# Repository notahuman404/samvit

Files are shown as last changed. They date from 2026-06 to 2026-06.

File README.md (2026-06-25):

# Samvit 👁️🌉

> *Samvit (संवित्) — Sanskrit for "Conscious Awareness"*

> **"We don't just navigate the system for blind users — we navigate the world."**

An AI-powered assistive system that helps visually impaired individuals independently find, understand, and physically reach public services — starting with healthcare.

---

## 🧩 The Problem

Visually impaired individuals face **two walls**, not one:

1. They can't independently navigate apps or screens to find nearby healthcare, benefits, or public services
2. Even when someone helps them find it — **they still can't get there alone**

Existing solutions solve neither problem completely. Screen readers tell you *what's on screen* but don't help you *understand* or *act*. Navigation apps help sighted people. Nothing bridges both worlds.

---

## 💡 The Solution

Samvit is a **two-layer assistive system** combining AI software and sensory hardware:

### 🧠 Layer 1 — Software (The Brain)
A Jarvis-like voice AI that understands your phone screen and the web on your behalf.

- Say *"Find me the nearest free clinic"* — it searches, reads, filters, and explains results in plain language
- Guides users through benefits eligibility questions conversationally
- Makes phone calls on command (*"Call the clinic and ask if they take walk-ins"*)
- Reads and interprets any screen content aloud with context, not just raw text

### 👁️ Layer 2 — Hardware (The Game-Changer)
A wearable sensory substitution device inspired by Neil Harbisson's pioneering work in human sensory extension.

- Uses **heatmapping** to translate the visual environment into sensory feedback
- Converts spatial information (obstacles, paths, destinations) into perceivable signals
- Allows the user to **physically navigate** to their destination — independently, without a guide
- Works in real-time alongside the software layer for end-to-end assistance

---

## 🎯 Challenge Alignment

**Brief 4 — Public Service, Direction A: Benefits Navigator**

| Requirement | Samvit |
|---|---|
| Help users interpret rules and reduce confusion | ✅ Voice AI simplifies eligibility criteria in plain language |
| Translate criteria into plain language | ✅ Reads and contextualizes screen content aloud |
| Ask questions to guide users through their situation | ✅ Conversational AI walks users step by step |
| Healthcare as a primary use case | ✅ Core use case of the product |
| Go beyond a directory — help users actually act | ✅ Hardware ensures they can physically reach the service |

---

## 🏗️ Architecture Overview

```
User Voice Input
      │
      ▼
┌─────────────────────┐
│   Voice AI Layer    │  ← Understands intent, reads screen, navigates web
│  (Jarvis Engine)    │
└────────┬────────────┘
         │
         ▼
┌─────────────────────┐
│  Screen & Web       │  ← Finds clinics, reads eligibility, makes calls
│  Understanding      │
└────────┬────────────┘
         │
         ▼
┌─────────────────────┐
│  Hardware Layer     │  ← Heatmap-based sensory substitution wearable
│  (Sensory Bridge)   │    guides user to physical destination
└─────────────────────┘
```

---

## 🔬 Inspiration

- **Neil Harbisson** — Pioneer of sensory substitution; the first human officially recognized as a cyborg, who perceives color through sound via his "eyeborg" antenna
- **Sensory Substitution Research** — The science of routing one sense's information through another (e.g., visual data → tactile or auditory feedback)
- **Heatmap Navigation** — Using thermal/spatial density mapping to encode environmental information into perceivable signals

---

## 🔩 Hardware Validation & Testing

Our hardware pipeline — from depth sensing through motor actuation — has been validated through a **datasheet-driven simulation** that goes well beyond simple mocking. Rather than stubbing out I2C calls and calling it tested, we built physically-accurate models of every component in the signal chain and ran them against the actual firmware logic.

### What we validated

| Component | Validation Method |
|---|---|
| Intel RealSense D435i depth cameras | Noise model fitted to Intel's published accuracy data: quadratic noise growth (σ = 2mm at 1m, 8mm at 2m, 32mm at 4m), distance-dependent dropout rates, edge artifacts, flying pixel simulation |
| NXP PCA9685 motor drivers (×9) | Full I2C protocol verification against datasheet Rev.4: init sequence timing, register payload format, ALLCALL broadcast, 65-byte raw writes (bypassing SMBus 32-byte cap) |
| Dual-camera depth fusion | Min-distance overlap logic with statistically-verified output across 100+ noisy frames. Invalid readings (0) never corrupt fusion — verified with 50,000 samples |
| 144-motor grid (12×12) | Bijective channel mapping (144 → 9 boards × 16 channels), single-motor precision addressing, rapid on/off cycling stability |
| I2C bus (BCM2711 BSC, 400kHz) | Timing budget calculated from first principles (9 clocks/byte × 400kHz), bus utilization analysis, clock stretching model |

### Fault injection (not just happy-path)

The simulation injects real hardware failures and verifies graceful degradation:

- **Board failure isolation** — one PCA9685 dies, the other 8 continue operating (128/144 motors still active)
- **Brown-out detection** — supply drops below 2.7V, bus operations halt safely before corrupting registers
- **Stuck I2C bus** — SCL held low (common with loose connections), detected and reported within one transaction attempt
- **Bus contention (NACK storms)** — 5% random NACK rate with retry logic achieves 100% frame delivery
- **Thermal performance** — I2C transactions validated at 70°C operating temperature with oscillator drift model

### Stress testing

- **1,000 continuous frames** with dynamically moving obstacles — zero errors, 0.28ms avg loop time (99.4% headroom on 50ms budget)
- **500 rapid on/off cycles** — verifies register write stability under worst-case duty cycling
- **Bug regression suite** — 3 previously-identified firmware bugs verified fixed (SMBus cap #11, ALLCALL bit #12, invalid-depth mapping #13)

### How to run

```bash
cd hardware/tests
python hil_simulation.py --verbose
```

Outputs a structured JSON report (`hil_results.json`) suitable for CI integration, with per-test metrics, timing data, and pass/fail status.

---

## 🚀 MVP Scope

**Phase 1 — Software MVP**
- [x] Voice-activated screen reader with contextual understanding
- [x] Healthcare clinic finder with eligibility pre-screening
- [x] Conversational benefits guidance flow
- [x] One-tap call routing to clinics/services
- [x] Agentic flow: multi-step goal execution with voice control

**Phase 2 — Hardware Prototype**
- [x] Wearable sensor unit (C++ firmware, ARM-compiled)
- [x] Heatmap generation from dual depth cameras
- [x] Sensory feedback output (144 vibration motors, 12×12 grid)
- [x] Integration with software navigation layer
- [x] Hardware validation suite (22 tests, datasheet-verified)

---

## 👥 Target Users

- Visually impaired individuals (partial or full vision loss)
- Blind individuals navigating public services independently
- Families assisting visually impaired members remotely
- Community organizations supporting disability access

---

## 🌍 Impact

Every other Benefits Navigator is just an app. Samvit goes further:

- **Finds** the nearest relevant service
- **Explains** eligibility in plain language
- **Calls** on your behalf
- **Gets you there** — physically, independently

This isn't just accessibility software. It's **independence as a service.**

---

## 🛠️ Running Locally

### Prerequisites

- [Android Studio](https://developer.android.com/studio) (Ladybug or newer recommended)
- Python 3.10+ (for backend)
- A [Gemini API key](https://aistudio.google.com/apikey) (free tier works)
- A `google-services.json` from your GenAI project (for GenAI AI SDK)

### Step 1 — Clone the repo

```bash
git clone https://github.com/mrehan0516/Vision_Guide.git
cd Vision_Guide
```

### Step 2 — Set up the Gemini API key

Create a `.env` file in the project root (same level as `settings.gradle.kts`):

```bash
cp .env.example .env
```

Edit `.env` and replace the placeholder with your real key:

```
GEMINI_API_KEY=your_actual_gemini_api_key_here
```

This key is used by both the Android app (via the Secrets Gradle Plugin) and the Python backend.

### Step 3 — GenAI setup

Place your `google-services.json` file in the `app/` directory. You can get this from your [GenAI Console](https://console.firebase.google.com/) → Project Settings → General → Your Apps → Download `google-services.json`.

### Step 4 — Run the Android app

1. Open Android Studio
2. Select **Open** and choose the `Vision_Guide` directory
3. Let Gradle sync complete (it will download all dependencies automatically)
4. If you see a signing config error, remove this line from `app/build.gradle.kts`:
   ```
   signingConfig = signingConfigs.getByName("debugConfig")
   ```
5. Connect a physical Android device (recommended — accessibility features work best on real devices) or start an emulator
6. Click **Run** (green play button) or press `Shift+F10`

> **Note:** The app uses a `MockVisionPilotClient` by default, so it works without the backend running. The mock simulates the full agent plan → step → confirm flow for demo purposes.

### Step 5 — Run the backend (optional, for full Gemini-powered agent)

```bash
cd backend
pip install fastapi uvicorn google-generativeai pydantic
```

Set the API key in your terminal:

```bash
export GEMINI_API_KEY=your_actual_gemini_api_key_here
```

Start the server:

```bash
python main.py
```

The backend runs on `http://localhost:8000`. API docs are available at `http://localhost:8000/docs`.

### Step 6 — Run the hardware simulation (no hardware needed)

```bash
cd hardware/tests
python hil_simulation.py --verbose
```

This runs the full 22-test HIL validation suite and outputs results to `hil_results.json`.

### Quick reference — what runs where

| Component | How to run | Needs hardware? |
|---|---|---|
| Android app (mock mode) | Android Studio → Run | No (phone or emulator) |
| Android app (live agent) | Android Studio → Run + backend on | No (phone + laptop) |
| Backend API | `python main.py` | No |
| Hardware simulation | `python hil_simulation.py` | No |
| Haptic vest firmware | `./haptic_vest` (on RPi4) | Yes (RPi4 + cameras + motors) |

---

## 🙏 Credits & Acknowledgments

### AI Tools Used in Development

| Tool | Role | Tier |
|---|---|---|
| **Google Gemini 2.0 Flash** | Core AI backbone — powers the agentic reasoning engine, screen understanding, multimodal vision (screenshot OCR), goal decomposition, and step planning | Free tier |
| **Devin** (by Cognition AI) | AI software engineer — built the C++ firmware port, HIL simulation suite, agentic backend (`agent.py`), and Android integration | Free tier |
| **Claude** (by Anthropic) | AI assistant — helped with architecture planning, code review, and documentation | Free tier |

### Open-Source Libraries & Frameworks

**Android App:**
| Library | Purpose |
|---|---|
| [Jetpack Compose](https://developer.android.com/jetpack/compose) | Declarative UI framework |
| [GenAI AI](https://firebase.google.com/docs/vertex-ai) | Gemini model access via GenAI |
| [Retrofit](https://square.github.io/retrofit/) + [OkHttp](https://square.github.io/okhttp/) | HTTP client for backend communication |
| [Moshi](https://github.com/square/moshi) | JSON serialization |
| [CameraX](https://developer.android.com/training/camerax) | Camera capture pipeline |
| [Kotlin Coroutines](https://kotlinlang.org/docs/coroutines-overview.html) | Async/concurrent programming |
| [Accompanist Permissions](https://google.github.io/accompanist/permissions/) | Runtime permission handling |
| [Room](https://developer.android.com/training/data-storage/room) | Local database |
| [Navigation Compose](https://developer.android.com/jetpack/compose/navigation) | In-app navigation |

**Backend (Python):**
| Library | Purpose |
|---|---|
| [FastAPI](https://fastapi.tiangolo.com/) | REST API framework |
| [google-generativeai](https://github.com/google-gemini/generative-ai-python) | Gemini API client |
| [Pydantic](https://docs.pydantic.dev/) | Data validation & serialization |
| [Uvicorn](https://www.uvicorn.org/) | ASGI server |

**Hardware Firmware (C++):**
| Library | Purpose |
|---|---|
| [Intel RealSense SDK (librealsense2)](https://github.com/IntelRealSense/librealsense) | Dual D435i depth camera capture |
| [CMake](https://cmake.org/) | Cross-platform build system |
| C++ Standard Library (`std::thread`, `std::mutex`) | Threading & synchronization |
| Linux I2C (`i2c-dev`, `I2C_RDWR` ioctl) | Raw I2C communication with PCA9685 boards |

**Hardware Components:**
| Component | Spec |
|---|---|
| Raspberry Pi 4B | Cortex-A72, BCM2711, I2C Fast Mode (400kHz) |
| Intel RealSense D435i (×2) | Stereo depth cameras, 640×480 @ 30fps |
| NXP PCA9685 (×9) | 16-channel 12-bit PWM drivers |
| ERM Vibration Motors (×144) | 12×12 haptic grid, 3V/75mA each |

### Methodology Note

The hardware simulation (`hardware/tests/hil_simulation.py`) uses noise models and timing parameters derived from published datasheets — not arbitrary mock values. All protocol sequences were validated against NXP PCA9685 Datasheet Rev.4 (2015) and Intel RealSense D435i specifications (2019).

---

## 📄 License

MIT License — Open for contribution and community development.

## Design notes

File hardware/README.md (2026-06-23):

# Haptic Feedback Vest — Hardware Design

144-channel vibrotactile vest driven by a Raspberry Pi 4, two Intel RealSense D435i depth cameras, and nine PCA9685 PWM controllers switching AO3400A MOSFETs into Precision Microdrives 310-113 ERM coin motors.

## Directory Layout

```
hardware/
├── README.md                       ← this file
├── bom/
│   ├── bom-master.csv              ← full consolidated BOM
│   └── bom-notes.md                ← sourcing notes, substitutions, tolerances
├── schematics/
│   ├── top-level-block-diagram.md  ← system block diagram (ASCII)
│   ├── motor-driver-cell.md        ← single MOSFET driver cell (repeat ×144)
│   ├── pca9685-chain.md            ← I2C chain and addressing
│   ├── power-tree.md               ← full power distribution tree
│   └── raspberry-pi-pinout.md      ← Pi GPIO assignments
├── assembly/
│   ├── assembly-guide.md           ← step-by-step build sequence
│   ├── motor-grid-layout.md        ← 12×12 grid, numbering, spacing
│   └── connector-plan.md           ← JST, FFC, USB connector specs
├── firmware-notes/
│   ├── motor-addressing.md         ← PCA9685 → motor index mapping
│   └── latency-budget.md           ← pipeline timing to hit <50 ms
└── tests/
    └── validation-procedures.md    ← hardware smoke tests and validation
```

## Quick-Start Summary

| Item | Value |
|---|---|
| Haptic channels | 144 |
| Motor grid | 12 × 12 |
| PWM controllers | 9 × PCA9685 (I2C) |
| MOSFET switches | 144 × AO3400A |
| Depth sensors | 2 × Intel RealSense D435i (USB 3) |
| Compute | Raspberry Pi 4 4 GB |
| Audio amp | MAX98357A (I2S) |
| Motor supply | 3 V rail |
| Logic supply | 5 V rail |
| Estimated peak draw | ~31 W |
| Estimated average draw | ~16 W |
| Target power bank | 65 W USB-C PD, ≥ 20 000 mAh |
| Target end-to-end latency | < 50 ms |

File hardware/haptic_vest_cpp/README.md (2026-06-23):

# Haptic Vest C++ — Production Port

C++ port of the Python haptic vest control pipeline (Raspberry Pi 4, dual Intel RealSense D435i, 9× PCA9685, 144 ERM motors).

## Building (on Raspberry Pi 4 / ARM Linux)

```bash
sudo apt install cmake librealsense2-dev
mkdir build && cd build
cmake ..
make -j4
```

The binary is `build/haptic_vest`.

## Usage

```bash
# Real hardware (Pi with cameras + I2C boards):
./haptic_vest

# Mock mode (no hardware):
./haptic_vest --mock

# Options:
./haptic_vest --mock -n 100 -v          # 100 iterations, verbose stats
./haptic_vest --hz 30                   # 30 Hz loop rate
./haptic_vest --upper-serial XXXX --lower-serial YYYY
```

## File Layout

| File | Description |
|---|---|
| `config.h` | All shared constants (grid size, I2C addresses, PCA9685 registers, thresholds) |
| `camera_fusion.h/.cpp` | Threaded dual D435i capture + min-distance overlap fusion |
| `depth_processing.h/.cpp` | Depth grid → motor intensity mapping with invalid-pixel masking |
| `motor_driver.h/.cpp` | PCA9685 I2C driver using raw `I2C_RDWR` ioctl (no SMBus 32-byte cap) |
| `connector.h/.cpp` | Master orchestrator: init → loop → shutdown |
| `main.cpp` | CLI entry point with signal handling |
| `CMakeLists.txt` | Build configuration |
| `compiled/` | Pre-compiled binary (built on x86_64 Ubuntu 22.04; rebuild on Pi for ARM) |

## Behavioral Differences from Python Version

1. **Downsampling moved into CameraSource**: In Python, `DualCameraFusion.get_fused_grid()` calls `_downsample_to_grid()` on each raw frame. In C++, each `RealSenseCamera` downsamples inside its capture thread (before writing to the shared buffer), so the main loop never touches raw high-resolution frames. This reduces lock contention and avoids copying large frames across threads.

2. **No `pyrealsense2` wrapper — uses librealsense2 C++ API directly**: Same SDK, just the native C++ bindings instead of the Python wrapper. Behavior is identical.

3. **I2C uses `I2C_RDWR` ioctl directly**: Python used `smbus2.i2c_msg.write()` which internally does the same ioctl. The C++ version calls `ioctl(fd, I2C_RDWR, ...)` directly — identical wire behavior, no library dependency.

4. **Performance**: Mock-mode loop time is ~0.03 ms (vs ~2.75 ms in Python). Real-hardware I2C timing will be identical (I2C bus speed is the bottleneck, not CPU).

5. **No `--diag` mode**: The Python `connector.py` had a `--diag` flag that scanned the I2C bus. The C++ port omits this — use `i2cdetect -y 1` directly on the Pi instead.

6. **Signal handling**: Uses `std::signal(SIGINT/SIGTERM)` for clean shutdown. Same behavior as the Python version's signal handler.

## Note on Pre-compiled Binary

The binary in `compiled/` was built on **x86_64 Ubuntu 22.04** (Devin's build environment). You must **rebuild on your Raspberry Pi 4** (ARM) for it to run on the actual hardware. The source code and CMakeLists.txt are ready for a Pi build with no changes needed.

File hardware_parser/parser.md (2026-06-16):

# HWDL — Hardware Description Language Specification
## Version 1.0 | Compiler Design & Language Reference

---

## 1. Language Goals

### What HWDL Is

HWDL (Hardware Description Language) is a **strict, declarative DSL** for describing electronic hardware at the logical schematic level. It captures:

- Component definitions (parts) and their pin interfaces
- Power domains and their electrical properties
- Named net connectivity between component pins
- Modules (reusable subsystems) containing instances and connections
- Constraints, placement hints, routing hints, and simulation/validation metadata
- Compile targets that downstream tooling (schematic, PCB, netlist generators) will consume

HWDL is designed to be generated by AI agents and parsed by deterministic compiler tooling. Every construct has a single, unambiguous interpretation.

### What HWDL Is Not

- Not an RTL/HDL language (no Verilog/VHDL behavioral semantics)
- Not a netlist format (HWDL compiles *to* a structured IR from which netlists are generated)
- Not a PCB layout tool (placement/routing hints are advisory only)
- Not a simulation language (simulation blocks carry metadata for external tools)
- Not a schematic drawing tool (topology only; visual layout is downstream)

### Design Principles

1. **No ambiguity**: every syntactic construct has exactly one parse.
2. **No implicit behavior**: all connections, domains, and references are explicit.
3. **Fail loudly**: invalid input produces a precise, located diagnostic.
4. **AI-safe**: structure prevents generation of syntactically plausible but semantically broken designs.
5. **Minimal surface area**: every keyword earns its place.

---

## 2. Syntax Design

### Choice: Custom Block Syntax (Curly-Brace / Semicolon)

| Option | Rejected reason |
|---|---|
| YAML | Significant whitespace causes generation errors; no block comments; indentation levels fragile |
| JSON | No comments; extremely verbose; no typed physical values; no procedural constructs |
| TOML | Flat tables only; no nested block structure needed for hierarchical modules |
| S-expressions | Unfamiliar to engineers; parenthesis matching fragile for AI generation |
| **Custom** | Explicit braces for scope; semicolons for statement termination; no significant whitespace; physical units as first-class literals; minimal keyword set |

The syntax is deterministic for recursive-descent parsing. No backtracking is needed.

### Minimal Complete Example

```hwdl
hwdl 1.0;

// === Part declarations (component library entries) ===

part "ATmega328P" {
    vendor: "Microchip";
    package: "DIP-28";
    datasheet: "https://example.com/atmega328p.pdf";
    pins {
        VCC:   power_in;
        GND:   power_gnd;
        AVCC:  power_in;
        AREF:  passive;
        RESET: input;
        PB0:   bidir;
        PB1:   bidir;
        TX:    output;
        RX:    input;
    }
}

part "GEN_CAP" {
    vendor: "generic";
    package: "0402";
    pins {
        P: passive;
        N: passive;
    }
}

// === Power domain declarations ===

power 3V3 {
    voltage: 3.3V;
    tolerance: 5%;
    max_current: 500mA;
}

power GND {
    voltage: 0V;
    type: "reference";
}

// === Module declaration ===

module MCU_Core {
    // Instance declarations
    U1: "ATmega328P";
    C1: "GEN_CAP" { value: 100nF; voltage_rating: 10V; }
    C2: "GEN_CAP" { value: 10uF;  voltage_rating: 10V; }

    // Explicit net declarations
    net uart_tx;
    net uart_rx;

    // Power connections
    connect U1.VCC  -> power.3V3;
    connect U1.GND  -> power.GND;
    connect U1.AVCC -> power.3V3;
    connect U1.AREF -> power.GND;
    connect C1.P    -> power.3V3;
    connect C1.N    -> power.GND;
    connect C2.P    -> power.3V3;
    connect C2.N    -> power.GND;

    // Signal connections
    connect U1.TX -> uart_tx;
    connect U1.RX -> uart_rx;

    // Electrical constraint metadata
    constraint {
        max_current:     200mA;
        operating_temp:  -40C to 85C;
        supply_voltage:  3.0V to 3.6V;
    }

    // Advisory placement hints (consumed by layout tool)
    placement {
        C1.near: "U1";
        C2.near: "U1";
        region:  "center";
    }

    // Advisory routing hints
    routing {
        power.3V3.width: 0.5mm;
        power.GND.width: 0.5mm;
        priority:        "power_first";
    }

    // Validation metadata (for ERC/DRC tooling)
    validate {
        erc:            true;
        drc:            true;
        footprint_check: true;
    }

    // Simulation metadata (for SPICE / other tools)
    simulate {
        model:     "spice";
        transient: "0s to 10ms";
        step:      1us;
    }
}

// === Compile target declaration ===

target kicad_v6 {
    format:     "kicad_v6";
    layers:     2;
    board_size: "50mm x 80mm";
}
```

---

## 3. Grammar

### 3.1 Notation

This grammar uses EBNF with these conventions:

- `::=` — production rule
- `|` — alternation
- `( ... )` — grouping
- `[ ... ]` — optional (zero or one)
- `{ ... }` — zero or more
- `"..."` — terminal literal
- `UPPER_CASE` — lexical token

### 3.2 File Structure

```ebnf
file            ::= version_decl top_decl* EOF

version_decl    ::= "hwdl" VERSION_LIT ";"
VERSION_LIT     ::= DIGIT+ "." DIGIT+
```

### 3.3 Top-Level Declarations

```ebnf
top_decl        ::= part_decl
                  | power_decl
                  | net_decl
                  | module_decl
                  | target_decl
```

### 3.4 Part Declaration

```ebnf
part_decl       ::= "part" STRING_LIT "{" part_item* "}"
part_item       ::= attr_stmt
                  | pin_block

pin_block       ::= "pins" "{" pin_stmt* "}"
pin_stmt        ::= IDENT ":" pin_dir ";"

pin_dir         ::= "power_in"
                  | "power_out"
                  | "power_gnd"
                  | "input"
                  | "output"
                  | "bidir"
                  | "passive"
                  | "open_drain"
                  | "no_connect"
```

### 3.5 Power Declaration

```ebnf
power_decl      ::= "power" IDENT "{" attr_stmt* "}"
```

### 3.6 Net Declaration

```ebnf
net_decl        ::= "net" IDENT ";"
```

### 3.7 Module Declaration

```ebnf
module_decl     ::= "module" IDENT "{" module_item* "}"

module_item     ::= instance_decl
                  | net_decl
                  | connect_stmt
                  | constraint_block
                  | placement_block
                  | routing_block
                  | validate_block
                  | simulate_block
```

### 3.8 Instance Declaration

```ebnf
instance_decl   ::= IDENT ":" STRING_LIT [ "{" attr_stmt* "}" ] ";"
```

The optional `{ attr_stmt* }` block overrides part-level attributes for this instance (e.g., component value, voltage rating). Instance `attr_stmt` keys must match attributes defined in the part declaration or be recognized generic attributes (`value`, `voltage_rating`, `tolerance`).

### 3.9 Connection Statement

```ebnf
connect_stmt    ::= "connect" endpoint "->" endpoint ";"

endpoint        ::= power_ref
                  | pin_ref
                  | net_ref

power_ref       ::= "power" "." IDENT
pin_ref         ::= IDENT "." IDENT
net_ref         ::= IDENT
```

**Disambiguation rule** (applied by the parser in order):
1. If the token sequence is `"power" "." IDENT` → `power_ref`
2. If the token sequence is `IDENT "." IDENT` → `pin_ref`
3. If the token is `IDENT` alone → `net_ref`

Restriction: The **left** endpoint of `->` must always be a `pin_ref`. The **right** endpoint may be `power_ref`, `net_ref`, or `pin_ref`. If right is `pin_ref`, an implicit net is created (valid only if both pins appear in no other connect statement assigning them to a different net).

### 3.10 Block Declarations

```ebnf
constraint_block ::= "constraint" "{" attr_stmt* "}"
placement_block  ::= "placement"  "{" attr_stmt* "}"
routing_block    ::= "routing"    "{" attr_stmt* "}"
validate_block   ::= "validate"   "{" attr_stmt* "}"
simulate_block   ::= "simulate"   "{" attr_stmt* "}"
```

Each block may appear at most once per module. The IR records all attribute key-value pairs verbatim for downstream consumption.

### 3.11 Target Declaration

```ebnf
target_decl     ::= "target" IDENT "{" attr_stmt* "}"
```

### 3.12 Attribute Statements

```ebnf
attr_stmt       ::= attr_key ":" attr_val ";"

attr_key        ::= IDENT [ "." IDENT ]

attr_val        ::= STRING_LIT
                  | range_val
                  | phys_val
                  | BOOL_LIT
                  | list_val
                  | IDENT

range_val       ::= phys_val "to" phys_val
phys_val        ::= num_lit UNIT
list_val        ::= "[" [ attr_val { "," attr_val } ] "]"
```

**`range_val` parse rule**: `phys_val "to" phys_val` is recognized only when the token after the first `phys_val` is the keyword `to`. If the `UNIT` of `low` and `high` differ, a type error is emitted.

### 3.13 Lexical Tokens

```ebnf
IDENT           ::= ALPHA { ALPHA | DIGIT | "_" }
                    (* must not be a reserved keyword *)

STRING_LIT      ::= '"' { CHAR } '"'
CHAR            ::= [^"\n\\] | "\\" ( '"' | "\\" | "n" | "t" )
BOOL_LIT        ::= "true" | "false"
num_lit         ::= [ "-" ] DIGIT+ [ "." DIGIT+ ]
                    [ ( "e" | "E" ) [ "+" | "-" ] DIGIT+ ]
ALPHA           ::= [A-Za-z_]
DIGIT           ::= [0-9]

UNIT            ::= "V"   | "mV"  | "uV"
                  | "A"   | "mA"  | "uA"  | "nA"
                  | "Ohm" | "kOhm"| "MOhm"
                  | "F"   | "uF"  | "nF"  | "pF"
                  | "H"   | "mH"  | "uH"  | "nH"
                  | "Hz"  | "kHz" | "MHz" | "GHz"
                  | "W"   | "mW"
                  | "mm"  | "cm"  | "um"  | "mil"
                  | "s"   | "ms"  | "us"  | "ns"  | "ps"
                  | "C"
                  | "%"

COMMENT         ::= "//" { [^\n] } "\n"?
WHITESPACE      ::= { " " | "\t" | "\r" | "\n" }+
(* COMMENT and WHITESPACE are discarded by the lexer *)
```

### 3.14 Reserved Keywords

The following identifiers are **reserved** and may not be used as `IDENT` in any context:

```
hwdl  part  power  module  net  connect  constraint
placement  routing  validate  simulate  target  pins
to  true  false
```

The following are reserved as **pin direction keywords** (valid only inside `pin_block`):

```
power_in  power_out  power_gnd  input  output  bidir
passive  open_drain  no_connect
```

> **Implementation note**: Pin direction keywords may be implemented as context-sensitive keywords (only reserved inside a `pin_block`) to allow their use as instance names elsewhere. However, forbidding them globally is simpler and recommended for v1.0.

---

## 4. AST Design

### 4.1 Source Location

Every AST node carries a `SourceLoc` for error reporting:

```python
@dataclass(frozen=True)
class SourceLoc:
    file: str    # absolute path to source file
    line: int    # 1-based line number
    col: int     # 1-based column number of first character
```

### 4.2 Node Types

```python
# ─── Root ────────────────────────────────────────────────────────────────────

@dataclass
class File:
    version:   "VersionDecl"
    top_decls: list["TopDecl"]  # PartDecl | PowerDecl | NetDecl | ModuleDecl | TargetDecl
    source:    str              # file path
    loc:       SourceLoc

@dataclass
class VersionDecl:
    major: int
    minor: int
    loc:   SourceLoc

# ─── Part ────────────────────────────────────────────────────────────────────

@dataclass
class PartDecl:
    name:  str            # from STRING_LIT (unquoted)
    attrs: list["AttrStmt"]
    pins:  list["PinStmt"]
    loc:   SourceLoc

@dataclass
class PinStmt:
    name:      str   # IDENT
    direction: str   # one of the 9 pin_dir values
    loc:       SourceLoc

# ─── Power ───────────────────────────────────────────────────────────────────

@dataclass
class PowerDecl:
    name:  str            # IDENT
    attrs: list["AttrStmt"]
    loc:   SourceLoc

# ─── Net ─────────────────────────────────────────────────────────────────────

@dataclass
class NetDecl:
    name: str   # IDENT
    loc:  SourceLoc

# ─── Module ──────────────────────────────────────────────────────────────────

@dataclass
class ModuleDecl:
    name:  str
    items: list["ModuleItem"]   # union of item types below
    loc:   SourceLoc

@dataclass
class InstanceDecl:
    ref_name:  str              # local name (U1, C1…)
    part_name: str              # part STRING_LIT (unquoted)
    overrides: list["AttrStmt"]
    loc:       SourceLoc

@dataclass
class ConnectStmt:
    src: "Endpoint"             # always PinRef in v1.0
    dst: "Endpoint"
    loc: SourceLoc

# Endpoint union
@dataclass
class PinRef:
    instance: str   # IDENT (left side of dot)
    pin:      str   # IDENT (right side of dot)
    loc:      SourceLoc

@dataclass
class PowerRef:
    domain: str   # IDENT after "power."
    loc:    SourceLoc

@dataclass
class NetRef:
    name: str   # IDENT
    loc:  SourceLoc

@dataclass
class ConstraintBlock:
    attrs: list["AttrStmt"]
    loc:   SourceLoc

@dataclass
class PlacementBlock:
    attrs: list["AttrStmt"]
    loc:   SourceLoc

@dataclass
class RoutingBlock:
    attrs: list["AttrStmt"]
    loc:   SourceLoc

@dataclass
class ValidateBlock:
    attrs: list["AttrStmt"]
    loc:   SourceLoc

@dataclass
class SimulateBlock:
    attrs: list["AttrStmt"]
    loc:   SourceLoc

# ─── Target ──────────────────────────────────────────────────────────────────

@dataclass
class TargetDecl:
    name:  str
    attrs: list["AttrStmt"]
    loc:   SourceLoc

# ─── Attributes ──────────────────────────────────────────────────────────────

@dataclass
class AttrStmt:
    key:   "AttrKey"
    value: "AttrVal"   # union below
    loc:   SourceLoc

@dataclass
class AttrKey:
    parts: list[str]   # 1 or 2 elements (dotted key)
    loc:   SourceLoc

# AttrVal union:
@dataclass
class StringVal:
    value: str
    loc:   SourceLoc

@dataclass
class PhysVal:
    number: float
    unit:   str
    loc:    SourceLoc

@dataclass
class RangeVal:
    low:  PhysVal
    high: PhysVal
    loc:  SourceLoc

@dataclass
class BoolVal:
    value: bool
    loc:   SourceLoc

@dataclass
class ListVal:
    items: list["AttrVal"]
    loc:   SourceLoc

@dataclass
class IdentVal:
    name: str     # bare IDENT used as value
    loc:  SourceLoc
```

### 4.3 Source Location Preservation Strategy

- The **lexer** attaches a `SourceLoc` to every token.
- The **parser** reads the `SourceLoc` from the **first token** consumed for each production and stores it on the resulting AST node.
- The `loc` field is **never derived or computed** — it always reflects the exact source position of the opening token of the construct.
- Multi-line constructs store only the start location; end location is omitted (can be added in v1.1 if diagnostics require spans).

---

## 5. Semantic Rules

### 5.1 Scope Rules

| Rule | Code | Description |
|---|---|---|
| SR-01 | E201 | Every `part` name (STRING_LIT) must be unique across the file. |
| SR-02 | E202 | Every `power` domain name must be unique across the file. |
| SR-03 | E203 | Every `module` name must be unique across the file. |
| SR-04 | E204 | Every `target` name must be unique across the file. |
| SR-05 | E205 | Within a module, every instance `ref_name` must be unique. |
| SR-06 | E206 | Within a module, every `net` name must be unique (and distinct from instance names). |
| SR-07 | E207 | A `net` name may not shadow a `power` domain name. |

### 5.2 Reference Rules

| Rule | Code | Description |
|---|---|---|
| RR-01 | E210 | Every `instance_decl` part name must reference a declared `part`. |
| RR-02 | E211 | Every `connect` `pin_ref` instance name must reference a declared instance in the same module. |
| RR-03 | E212 | Every `connect` `pin_ref` pin name must exist in the referenced instance's part `pins` block. |
| RR-04 | E213 | Every `connect` `power_ref` domain name must reference a declared `power` domain. |
| RR-05 | E214 | Every `connect` `net_ref` must reference a `net` declared in the same module scope (explicit net declarations are required; undeclared net names are errors). |
| RR-06 | E215 | Instance override attribute keys must match attributes declared in the target part, or be one of: `value`, `voltage_rating`, `tolerance`, `part_number`. |

### 5.3 Connectivity Rules

| Rule | Code | Description |
|---|---|---|
| CR-01 | E220 | A single pin may appear on the **left side** of at most one `connect` statement. Connecting the same pin twice is an error. |
| CR-02 | E221 | A single pin may belong to at most one net. If two connect statements would assign the same pin to different nets, that is an error. |
| CR-03 | E222 | A module must contain at least one `connect` statement (a module with no connections is meaningless and likely an error). This is a **warning** W010, not an error. |
| CR-04 | E223 | A `net` declared in a module but connected to zero pins is a **warning** W011. |

### 5.4 Electrical Rules (ERC)

These are checked when `validate { erc: true; }` is present; they are also **always** checked and produce warnings if ERC validation is not explicitly disabled.

| Rule | Code | Description |
|---|---|---|
| ER-01 | E300 | A pin with direction `power_in` must connect to a `power_ref`. Connecting to a signal net is an error. |
| ER-02 | E301 | A pin with direction `power_gnd` must connect to a `power_ref` whose `voltage` is `0V` or whose `type` is `"reference"`. |
| ER-03 | E302 | A pin with direction `power_out` may not connect to another `power_out` pin on the same net. |
| ER-04 | E303 | A pin with direction `output` may not connect to another `output` pin on the same net. |
| ER-05 | E304 | A pin with direction `no_connect` must not appear in any `connect` statement. |
| ER-06 | E305 | A net with **only** `input` pins (no driving pin) produces warning W020 "undriven net". |
| ER-07 | E306 | A `power_in` pin not connected to any net produces warning W021 "floating power pin". |

### 5.5 Unit Compatibility Rules

| Rule | Code | Description |
|---|---|---|
| UC-01 | E310 | In a `range_val`, `low.unit` and `high.unit` must be from the **same physical dimension** (e.g., both voltage, both temperature). Mixing units (e.g., `3.3V to 85C`) is an error. |
| UC-02 | E311 | `power.voltage` must have a voltage unit (`V`, `mV`, `uV`). |
| UC-03 | E312 | `power.max_current` must have a current unit (`A`, `mA`, `uA`, `nA`). |
| UC-04 | E313 | `power.tolerance` must have unit `%`. |
| UC-05 | E314 | Instance override `value` for capacitors must have capacitance unit; for resistors, resistance unit. (Capacitor/resistor detection is by convention: parts named per SR-01 with known pin directions. **Assumption**: part naming convention is not enforced by the grammar; UC-05 is a best-effort check emitting W030.) |

### 5.6 Structural Rules

| Rule | Code | Description |
|---|---|---|
| ST-01 | E400 | Each block type (`constraint`, `placement`, `routing`, `validate`, `simulate`) may appear **at most once** per module. |
| ST-02 | E401 | A `pins` block may appear at most once per `part`. |
| ST-03 | E402 | A `part` with no `pins` block is valid but produces warning W040 "part has no pins". |
| ST-04 | E403 | The `version_decl` must be the **first** non-comment token in the file. |
| ST-05 | E404 | `target` declarations may only appear at the **top level** (not inside modules). |

### 5.7 Error Examples

**E201 — Duplicate part name**
```hwdl
hwdl 1.0;
part "R" { pins { A: passive; B: passive; } }
part "R" { pins { A: passive; } }  // ERROR E201 line 3
```
Diagnostic: `E201 [3:1] duplicate part name "R"; first declared at line 2`

**E212 — Unknown pin**
```hwdl
connect U1.MISO -> spi_miso;
```
If `U1`'s part has no pin `MISO`:
Diagnostic: `E212 [5:10] pin "MISO" does not exist on part "ATmega328P" (instance "U1")`

**E300 — Power pin on signal net**
```hwdl
net my_signal;
connect U1.VCC -> my_signal;  // VCC is power_in
```
Diagnostic: `E300 [7:5] pin "U1.VCC" has direction "power_in" but is connected to signal net "my_signal"; expected a power domain`

**E310 — Range unit mismatch**
```hwdl
operating_range: 3.3V to 85C;
```
Diagnostic: `E310 [12:22] range bounds have incompatible units: "V" (voltage) vs "C" (temperature)`

---

## 6. Compiler Pipeline

### 6.1 Overview

```
Source Text
    │
    ▼
┌─────────┐
│  Lexer  │  → Token stream + SourceLoc on each token
└─────────┘
    │
    ▼
┌─────────────────────┐
│  Parser (recursive  │  → AST (File node)
│  descent)           │
└─────────────────────┘
    │
    ▼
┌──────────────────────────┐
│  Semantic Validator      │  → Annotated AST or error list
│  (scope + ref + ERC)     │
└──────────────────────────┘
    │
    ▼
┌──────────────────┐
│  Resolver        │  → Part refs resolved; pin refs validated;
│                  │     net membership computed
└──────────────────┘
    │
    ▼
┌──────────────────┐
│  Normalizer      │  → Physical values in base units;
│                  │     auto-net names assigned;
│                  │     net merge (transitive closure)
└──────────────────┘
    │
    ▼
┌──────────────────┐
│  IR Emitter      │  → hwdl_ir.json
└──────────────────┘
```

### 6.2 Lexer

**Input**: source string + file path  
**Output**: `list[Token]`

```python
@dataclass
class Token:
    kind:  str       # see token kinds below
    value: str       # raw text as it appeared in source
    loc:   SourceLoc
```

**Token kinds**:

| Kind | Pattern |
|---|---|
| `KW_*` | Each reserved keyword (e.g., `KW_HWDL`, `KW_PART`) |
| `PINDIR_*` | Pin direction keywords |
| `IDENT` | `[A-Za-z_][A-Za-z0-9_]*` (not a keyword) |
| `STRING` | `"..."` (stored without quotes) |
| `VERSION` | `\d+\.\d+` |
| `NUMBER` | `[-]?\d+(\.\d+)?([eE][+-]?\d+)?` |
| `UNIT` | One of the unit strings (matched before IDENT) |
| `BOOL` | `true` / `false` |
| `ARROW` | `->` |
| `DOT` | `.` |
| `COLON` | `:` |
| `SEMICOLON` | `;` |
| `LBRACE` | `{` |
| `RBRACE` | `}` |
| `LBRACKET` | `[` |
| `RBRACKET` | `]` |
| `COMMA` | `,` |
| `EOF` | end of input |

**Lexer algorithm**:
1. Maintain `pos`, `line`, `col` cursors.
2. Skip whitespace and `//` comments (advance cursors accordingly).
3. At each position, attempt matches in this priority order:
   a. `//` → consume to end of line, loop
   b. `->` → ARROW
   c. Two-char sequences before single-char
   d. VERSION_LIT (digit+dot+digit) — only attempted after `hwdl` keyword context; **Assumption**: the lexer is context-free but VERSION_LIT is attempted greedily at `\d+\.\d+`; if it appears outside a version_decl, the parser emits E100.
   e. NUMBER: `-?\d+(\.\d+)?([eE][+-]?\d+)?` — attempt, but only if not followed by an IDENT char (to avoid lexing `3V` as `3` `V`).
   f. UNIT strings (longest match first, e.g., `kOhm` before `k`... units are matched only after a NUMBER token)
   g. Keywords (longest match first)
   h. IDENT
   i. STRING
   j. Punctuation

**Unit lexing rule**: After a NUMBER token, if the next characters match a UNIT string (from the ordered UNIT table, longest match first, no whitespace between), they are lexed as a UNIT token. This makes `100nF` lex as `NUMBER("100") UNIT("nF")`.

### 6.3 Parser

A **recursive descent parser** with one-token lookahead (LL(1) sufficient with the disambiguation rules in §3.9).

**Key parsing rules**:

- `parse_file()` → `File`
- `parse_top_decl()` → dispatches on current token kind
- `parse_part_decl()` → `PartDecl`
- `parse_module_decl()` → `ModuleDecl`
- `parse_module_item()` → dispatches on current keyword
- `parse_connect_stmt()` → `ConnectStmt`; calls `parse_endpoint()`
- `parse_endpoint()` → examines lookahead: `KW_POWER + DOT` → `PowerRef`; `IDENT + DOT` → `PinRef`; `IDENT` → `NetRef`
- `parse_attr_val()` → tries `range_val` (via tentative `phys_val` + `KW_TO`), then other forms
- `parse_phys_val()` → `NUMBER UNIT` (error if UNIT absent)

**Error recovery**: On a parse error, the parser emits a diagnostic and attempts to recover by consuming tokens until the next `;` or `}` (panic mode). This allows multiple errors to be reported in a single pass.

### 6.4 Semantic Validator

Runs over the AST in two sub-passes:

**Pass 1 — Symbol collection**:
- Build global symbol table: `parts`, `power_domains`, `modules`, `targets`
- Within each module: `instances`, `nets`
- Check uniqueness (SR-01 through SR-07)

**Pass 2 — Reference and ERC validation**:
- Resolve all `PinRef` instances and pins (RR-01, RR-02, RR-03)
- Resolve all `PowerRef` domains (RR-04)
- Resolve all `NetRef` names (RR-05)
- Check instance override keys (RR-06)
- Check connectivity rules (CR-01, CR-02)
- Check ERC rules (ER-01 through ER-07)
- Check unit compatibility (UC-01 through UC-05)
- Check structural rules (ST-01 through ST-05)

Both passes accumulate diagnostics in a `DiagList`. Compilation aborts (does not emit IR) if any `ERROR`-level diagnostics exist.

### 6.5 Resolver

**Input**: validated AST + symbol table  
**Output**: resolved AST with cross-references populated

Steps:
1. For each module, attach each `InstanceDecl` to its `PartDecl` node.
2. For each `ConnectStmt`, attach the `PinRef`'s `PartDecl.PinStmt` to the reference.
3. For each `PowerRef`, attach the `PowerDecl` node.
4. For each `NetRef`, attach the `NetDecl` node.

This produces a fully cross-referenced AST usable by the normalizer without further lookups.

### 6.6 Normalizer

**Net merger algorithm**:

1. Create a `net_registry`: `dict[net_name, list[PinEndpoint]]`
2. Initialize: for each `net_decl` in a module, create an empty entry.
3. For each `connect_stmt`:
   - Left is always `PinRef` → compute `pin_endpoint = (instance_name, pin_name)`
   - Right is `PowerRef` → use `"$power_{domain}"` as net name; add pin to that net
   - Right is `NetRef` → add pin to that net
   - Right is `PinRef` → generate auto-net name `"$auto_{index}"` (monotonic counter per module); add both pins to it
4. Check: if the same pin appears in two entries of `net_registry`, emit E221.
5. Compute transitive closure: if pin P is in net A via one connect, and P is also in net B via another (impossible after step 4 check), merge. (Step 4 prevents this; closure only needed if net aliasing is added in future versions.)

**Physical value normalization**:
- Convert all `PhysVal` to a canonical base unit for comparison:
  - Voltage → `V` (millivolt = ×0.001, microvolt = ×0.000001)
  - Current → `A`
  - Resistance → `Ohm`
  - Capacitance → `F`
  - etc.
- Store both original and normalized in IR.

**Auto-net naming**: sequential `$auto_0`, `$auto_1`, etc. per module. Names are prefixed with `$` to avoid collision with user net names (user identifiers cannot start with `$`).

### 6.7 IR Emitter

Serializes the normalized, resolved AST to JSON matching the schema in §7.

---

## 7. Intermediate Representation

### 7.1 Format

The IR is a single JSON object. It is self-describing, version-tagged, and contains all information needed for downstream schematic generation, PCB layout, simulation, and validation.

### 7.2 Schema

```json
{
  "ir_version": "1.0",
  "hwdl_version": "1.0",
  "source_file": "path/to/design.hwdl",

  "parts": {
    "<part_name>": {
      "vendor":    "<string>",
      "package":   "<string>",
      "datasheet": "<string | null>",
      "attrs": {
        "<key>": <attr_val>
      },
      "pins": {
        "<pin_name>": {
          "direction": "<pin_dir>"
        }
      },
      "source_loc": { "file": "<str>", "line": 0, "col": 0 }
    }
  },

  "power_domains": {
    "<domain_name>": {
      "voltage": { "value": 0.0, "unit": "V", "normalized_V": 0.0 },
      "tolerance": { "value": 5.0, "unit": "%", "normalized": 0.05 },
      "max_current": { "value": 0.0, "unit": "mA", "normalized_A": 0.0 },
      "attrs": {},
      "source_loc": { "file": "<str>", "line": 0, "col": 0 }
    }
  },

  "modules": {
    "<module_name>": {
      "instances": {
        "<ref_name>": {
          "part": "<part_name>",
          "overrides": {
            "<key>": <attr_val>
          },
          "source_loc": { "file": "<str>", "line": 0, "col": 0 }
        }
      },
      "nets": {
        "<net_name>": {
          "kind": "signal | power | auto",
          "power_domain": "<domain_name | null>",
          "pins": [
            { "instance": "<ref_name>", "pin": "<pin_name>" }
          ],
          "source_loc": { "file": "<str>", "line": 0, "col": 0 }
        }
      },
      "constraint": {
        "<key>": <attr_val>
      },
      "placement": {
        "<key>": <attr_val>
      },
      "routing": {
        "<key>": <attr_val>
      },
      "validate": {
        "<key>": <attr_val>
      },
      "simulate": {
        "<key>": <attr_val>
      },
      "source_loc": { "file": "<str>", "line": 0, "col": 0 }
    }
  },

  "targets": {
    "<target_name>": {
      "attrs": {
        "<key>": <attr_val>
      },
      "source_loc": { "file": "<str>", "line": 0, "col": 0 }
    }
  },

  "diagnostics": [
    {
      "code": "W010",
      "severity": "warning",
      "message": "module MCU_Core has no connect statements",
      "loc": { "file": "<str>", "line": 0, "col": 0 }
    }
  ]
}
```

### 7.3 `attr_val` IR Encoding

All `attr_val` AST nodes serialize to a JSON object with a `kind` discriminator:

```json
{ "kind": "string",  "value": "Microchip" }
{ "kind": "phys",    "value": 3.3, "unit": "V", "normalized": 3.3, "base_unit": "V" }
{ "kind": "range",   "low": <phys>, "high": <phys> }
{ "kind": "bool",    "value": true }
{ "kind": "list",    "items": [ <attr_val>, ... ] }
{ "kind": "ident",   "value": "power_first" }
{ "kind": "integer", "value": 2 }
```

`INTEGER` is produced when a `num_lit` has no decimal point and no exponent and no UNIT — e.g., `layers: 2;`.

### 7.4 Net `kind` Values

| kind | Meaning |
|---|---|
| `"signal"` | User-declared net (`net` keyword) |
| `"power"` | Net derived from a `power_ref` (name: `$power_{domain}`) |
| `"auto"` | Implicitly created by pin-to-pin connect (name: `$auto_{n}`) |

### 7.5 IR Guarantees for Consumers

A consumer receiving a valid IR (no errors in `diagnostics`) may rely on:

1. Every pin reference in `nets` resolves to an existing instance and pin.
2. Every instance references an existing part.
3. Every power net references an existing power domain.
4. No pin appears in more than one net.
5. Physical values are present in both original units and normalized base-unit form.
6. All `source_loc` fields are populated.

---

## 8. Error Model

### 8.1 Diagnostic Structure

```python
@dataclass
class Diagnostic:
    code:     str        # "E201", "W010", etc.
    severity: str        # "error" | "warning" | "info"
    message:  str        # human-readable description
    loc:      SourceLoc  # source location of the offending token
    context:  str | None # optional: e.g., "in module MCU_Core"
    hint:     str | None # optional fix suggestion
```

### 8.2 Severity Levels

| Severity | Meaning |
|---|---|
| `error` | Fatal; IR is not emitted; must be fixed |
| `warning` | Non-fatal; IR is emitted; should be reviewed |
| `info` | Informational; never blocks compilation |

### 8.3 Error Code Ranges

| Range | Category |
|---|---|
| E001–E099 | Lexer errors (unexpected character, unterminated string, invalid number) |
| E100–E199 | Parse errors (unexpected token, missing semicolon, mismatched braces) |
| E200–E299 | Scope & reference errors (undefined, duplicate) |
| E300–E399 | Type & unit errors |
| E400–E499 | Structural errors (duplicate blocks, wrong placement) |
| W001–W099 | Lexer warnings |
| W010–W099 | Semantic warnings (unconnected nets, no pins, etc.) |

### 8.4 Standard Error Codes

| Code | Message template |
|---|---|
| E001 | Unexpected character `{char}` at {loc} |
| E002 | Unterminated string literal |
| E003 | Invalid number literal `{text}` |
| E004 | Unknown unit `{text}`; expected one of: `{units}` |
| E100 | Expected `{expected}` but found `{found}` |
| E101 | Unexpected end of file; expected `{expected}` |
| E102 | Missing semicolon after `{construct}` |
| E103 | Unclosed `{delimiter}` opened at {open_loc} |
| E104 | `connect` left endpoint must be a pin reference (IDENT.IDENT) |
| E201 | Duplicate part name `{name}`; first declared at {prev_loc} |
| E202 | Duplicate power domain `{name}` |
| E203 | Duplicate module name `{name}` |
| E204 | Duplicate target name `{name}` |
| E205 | Duplicate instance name `{name}` in module `{module}` |
| E206 | Duplicate net name `{name}` in module `{module}` |
| E207 | Net name `{name}` shadows power domain of same name |
| E210 | Unknown part `{name}`; no `part` declaration found |
| E211 | Unknown instance `{name}` in module `{module}` |
| E212 | Pin `{pin}` does not exist on part `{part}` (instance `{inst}`) |
| E213 | Unknown power domain `{name}` |
| E214 | Unknown net `{name}` in module `{module}`; declare with `net {name};` |
| E215 | Instance override key `{key}` not recognized for part `{part}` |
| E220 | Pin `{inst}.{pin}` appears on the left side of multiple connect statements |
| E221 | Pin `{inst}.{pin}` would be assigned to two different nets: `{net1}` and `{net2}` |
| E300 | Pin `{inst}.{pin}` (direction: power_in) connected to signal net `{net}`; expected a power domain |
| E301 | Pin `{inst}.{pin}` (direction: power_gnd) must connect to a power domain with voltage 0V or type "reference" |
| E302 | Net `{net}` has multiple power_out pins: `{pins}` |
| E303 | Net `{net}` has multiple output pins: `{pins}` |
| E304 | Pin `{inst}.{pin}` has direction no_connect but appears in a connect statement |
| E310 | Range bounds have incompatible units: `{u1}` vs `{u2}` |
| E311 | Attribute `voltage` requires a voltage unit; got `{unit}` |
| E312 | Attribute `max_current` requires a current unit; got `{unit}` |
| E313 | Attribute `tolerance` requires unit `%`; got `{unit}` |
| E400 | Block `{block}` appears more than once in module `{module}` |
| E401 | `pins` block appears more than once in part `{part}` |
| E402 | `version_decl` must be the first statement in the file |
| E403 | `target` may only appear at top level, not inside a module |
| W010 | Module `{module}` has no connect statements |
| W011 | Net `{net}` in module `{module}` is declared but not connected to any pin |
| W020 | Net `{net}` has no driving pin (all pins are input/passive) |
| W021 | Pin `{inst}.{pin}` (direction: power_in) is not connected |
| W030 | Cannot verify unit compatibility for instance override `value` on part `{part}` |
| W040 | Part `{part}` has no `pins` block |

### 8.5 Error Output Format

```
ERROR E212 design.hwdl:14:12
  pin "MISO" does not exist on part "ATmega328P" (instance "U1")
  in module: MCU_Core
  hint: available pins are: VCC, GND, AVCC, AREF, RESET, PB0, PB1, TX, RX
```

The format is: `{SEVERITY} {CODE} {file}:{line}:{col}\n  {message}\n  {context}\n  {hint}`.

---

## 9. Versioning Strategy

### 9.1 Version Declaration

Every HWDL file declares its language version as the first statement:

```hwdl
hwdl 1.0;
```

The compiler checks: `(file_major, file_minor) <= (compiler_major, compiler_minor)`.

### 9.2 Compatibility Policy

| Change type | Version bump | Policy |
|---|---|---|
| Add new keyword | Minor (`1.0` → `1.1`) | Old files still parse; new keyword is optional |
| Add new block type | Minor | Old files compile; block is silently ignored if compiler version is lower |
| Add new pin direction | Minor | Older compilers emit W050 "unknown pin direction" |
| Add new built-in unit | Minor | Older compilers emit E004 |
| Remove keyword or construct | Major (`1.x` → `2.0`) | Old files may fail to compile against new compiler |
| Change semantic rule | Major | Must be clearly documented |
| Change IR schema | IR minor bump (separate) | IR version is independent of language version |

### 9.3 Compiler Version Registry

The compiler exports:
```python
HWDL_SUPPORTED_VERSIONS = [(1, 0)]  # list of (major, minor) tuples

def check_version(major: int, minor: int) -> bool:
    return (major, minor) in HWDL_SUPPORTED_VERSIONS
```

### 9.4 Forward-Compatibility Rule

If a file declares `hwdl 1.1` but the compiler only supports `hwdl 1.0`:
- Emit warning W001 `"file uses hwdl 1.1; compiler supports up to 1.0; unknown constructs will be skipped"`
- Continue parsing; emit errors only for constructs that cannot be parsed at all.

### 9.5 IR Versioning

The IR carries `"ir_version": "1.0"` independently. IR consumers should reject IR versions they do not recognize. The IR schema may be updated independently of the language version via a separate changelog.

---

## 10. Python Implementation Plan

### 10.1 Project Structure

```
hwdl/
├── __init__.py
├── lexer.py         # Lexer + Token + SourceLoc
├── ast_nodes.py     # All @dataclass AST node types
├── parser.py        # Recursive-descent parser
├── validator.py     # Semantic validator + symbol table
├── resolver.py      # Cross-reference resolution
├── normalizer.py    # Net merger + unit normalization
├── ir_emitter.py    # IR JSON emitter
├── diagnostics.py   # Diagnostic + DiagList
├── units.py         # Unit table + normalization functions
├── compiler.py      # Top-level compile() function
└── cli.py           # CLI entry point
```

### 10.2 Standard Library Only

No third-party dependencies required. The following stdlib modules are sufficient:

| Module | Use |
|---|-----|
| `dataclasses` | AST node definitions |
| `json` | IR serialization |
| `re` | Lexer token patterns |
| `enum` | Token kinds, pin directions, severity |
| `pathlib` | File path handling |
| `typing` | Type annotations |
| `sys`, `argparse` | CLI |

### 10.3 Lexer Implementation

```python
import re
from dataclasses import dataclass
from typing import Iterator

# Build a single compiled regex with named groups, ordered by priority
TOKEN_PATTERNS = [
    ("COMMENT",   r'//[^\n]*'),
    ("WHITESPACE",r'[ \t\r\n]+'),
    ("VERSION",   r'\d+\.\d+'),
    ("ARROW",     r'->'),
    ("NUMBER",    r'-?\d+(?:\.\d+)?(?:[eE][+-]?\d+)?(?=[ \t\r\n;,\[\]{}])'),
    ("UNIT",      r'(?:kOhm|MOhm|Ohm|mV|uV|mA|uA|nA|uF|nF|pF|mH|uH|nH|kHz|MHz|GHz|ms|us|ns|ps|mil|mm|cm|um|mW|V|A|F|H|Hz|W|s|C|%)'),
    ("BOOL",      r'true|false'),
    ("STRING",    r'"(?:[^"\\]|\\.)*"'),
    ("KEYWORD",   r'hwdl|part|power|module|net|connect|constraint|placement|routing|validate|simulate|target|pins|to|power_in|power_out|power_gnd|input|output|bidir|passive|open_drain|no_connect'),
    ("IDENT",     r'[A-Za-z_][A-Za-z0-9_]*'),
    ("DOT",       r'\.'),
    ("COLON",     r':'),
    ("SEMICOLON", r';'),
    ("LBRACE",    r'\{'),
    ("RBRACE",    r'\}'),
    ("LBRACKET",  r'\['),
    ("RBRACKET",  r'\]'),
    ("COMMA",     r','),
    ("MISMATCH",  r'.'),   # catch-all for E001
]

MASTER_RE = re.compile(
    '|'.join(f'(?P<{name}>{pattern})' for name, pattern in TOKEN_PATTERNS)
)
```

**Important**: UNIT must be matched before IDENT (longer patterns first within UNIT). The regex alternation handles this via ordering.

**NUMBER lookahead** (`(?=[ \t\r\n;,\[\]{}])`) ensures `-3.3` is not greedily consumed when followed by a UNIT (`-3.3V` → NUMBER(`-3.3`) + UNIT(`V`)).

Actually, a simpler approach: lex NUMBER and UNIT as a combined pattern when together, but separate them. The safest implementation: after tokenizing a NUMBER, if the very next token (no whitespace) matches a UNIT, pop it off and emit both. A two-step approach avoids lookahead complexity.

### 10.4 Parser Implementation

```python
class Parser:
    def __init__(self, tokens: list[Token], source: str):
        self.tokens = tokens
        self.pos = 0
        self.source = source
        self.diags: list[Diagnostic] = []

    def peek(self) -> Token:
        return self.tokens[self.pos]

    def consume(self, expected_kind: str | None = None) -> Token:
        tok = self.tokens[self.pos]
        if expected_kind and tok.kind != expected_kind:
            self.error(E100, tok, f"expected {expected_kind}, got {tok.kind}")
        self.pos += 1
        return tok

    def match(self, kind: str) -> bool:
        return self.peek().kind == kind

    def expect(self, kind: str) -> Token:
        return self.consume(kind)

    # ... parse_file, parse_part_decl, parse_module_decl, etc.
```

Each `parse_*` method:
1. Consumes the opening token
2. Recursively parses sub-productions
3. Consumes the closing token / semicolon
4. Returns an AST node with `loc` set to the opening token's `SourceLoc`

### 10.5 Validator Implementation

```python
@dataclass
class SymbolTable:
    parts:         dict[str, PartDecl]
    power_domains: dict[str, PowerDecl]
    modules:       dict[str, ModuleDecl]
    targets:       dict[str, TargetDecl]

@dataclass
class ModuleScope:
    instances: dict[str, InstanceDecl]
    nets:      dict[str, NetDecl]
    # Populated by resolver:
    pin_nets:  dict[tuple[str,str], str]  # (instance, pin) → net_name
```

The validator is a two-pass visitor over the AST. It accumulates all diagnostics before returning. It does **not** short-circuit on the first error (except for E101/E402 which make further parsing meaningless).

### 10.6 Unit Normalization Table

```python
# units.py
UNIT_DIMENSIONS = {
    # dimension → {unit → multiplier_to_base}
    "voltage":     {"V": 1.0, "mV": 1e-3, "uV": 1e-6},
    "current":     {"A": 1.0, "mA": 1e-3, "uA": 1e-6, "nA": 1e-9},
    "resistance":  {"Ohm": 1.0, "kOhm": 1e3, "MOhm": 1e6},
    "capacitance": {"F": 1.0, "uF": 1e-6, "nF": 1e-9, "pF": 1e-12},
    "inductance":  {"H": 1.0, "mH": 1e-3, "uH": 1e-6, "nH": 1e-9},
    "frequency":   {"Hz": 1.0, "kHz": 1e3, "MHz": 1e6, "GHz": 1e9},
    "power":       {"W": 1.0, "mW": 1e-3},
    "length":      {"mm": 1.0, "cm": 10.0, "um": 1e-3, "mil": 0.0254},
    "time":        {"s": 1.0, "ms": 1e-3, "us": 1e-6, "ns": 1e-9, "ps": 1e-12},
    "temperature": {"C": 1.0},
    "percent":     {"%": 1.0},
}

UNIT_TO_DIMENSION = {
    unit: dim
    for dim, units in UNIT_DIMENSIONS.items()
    for unit in units
}

BASE_UNIT = {dim: next(iter(units)) for dim, units in UNIT_DIMENSIONS.items()}
```

### 10.7 Top-Level `compile()` Function

```python
def compile(
    source: str,
    source_path: str = "<stdin>",
    emit_on_warning: bool = True,
) -> tuple[dict | None, list[Diagnostic]]:
    """
    Returns (ir_dict, diagnostics).
    ir_dict is None if any ERROR-level diagnostic was produced.
    """
    tokens = lex(source, source_path)
    ast    = parse(tokens, source_path)
    diags  = validate(ast)
    if any(d.severity == "error" for d in diags):
        return None, diags
    resolved   = resolve(ast)
    normalized = normalize(resolved)
    ir         = emit_ir(normalized, source_path, diags)
    return ir, diags
```

### 10.8 CLI

```
hwdl compile design.hwdl -o design_ir.json
hwdl lint design.hwdl
hwdl check-version design.hwdl
```

Implemented with `argparse`. Exit code 0 on success, 1 on errors.

### 10.9 Testing Strategy

Use `unittest` or `pytest`. Test fixtures: one `.hwdl` file per test case (valid or invalid). For valid files, assert IR JSON matches a golden `.json` fixture. For invalid files, assert specific error codes appear in diagnostics. Organize by section: `tests/lexer/`, `tests/parser/`, `tests/semantic/`, `tests/ir/`.

---

## 11. Reference Examples

### 11.1 Valid Example 1 — Resistor Voltage Divider

```hwdl
hwdl 1.0;

part "GEN_RES" {
    vendor: "generic";
    package: "0402";
    pins {
        A: passive;
        B: passive;
    }
}

power 5V {
    voltage: 5V;
    tolerance: 2%;
    max_current: 100mA;
}

power GND {
    voltage: 0V;
    type: "reference";
}

module VDivider {
    R1: "GEN_RES" { value: 10kOhm; }
    R2: "GEN_RES" { value: 10kOhm; }

    net vout;

    connect R1.A -> power.5V;
    connect R1.B -> vout;
    connect R2.A -> vout;
    connect R2.B -> power.GND;

    constraint {
        output_voltage: 2.5V;
        max_current:    500uA;
    }
}

target netlist_v1 {
    format: "spice_netlist";
}
```

### 11.2 Valid Example 2 — SPI Bus with Multiple Devices

```hwdl
hwdl 1.0;

part "SPI_MASTER" {
    vendor: "generic";
    package: "QFP-32";
    pins {
        VDD:  power_in;
        GND:  power_gnd;
        MOSI: output;
        MISO: input;
        SCK:  output;
        CS0:  output;
        CS1:  output;
    }
}

part "SPI_SLAVE" {
    vendor: "generic";
    package: "SOIC-8";
    pins {
        VCC:  power_in;
        GND:  power_gnd;
        SDI:  input;
        SDO:  output;
        CLK:  input;
        CS:   input;
    }
}

power 3V3 {
    voltage: 3.3V;
    tolerance: 3%;
    max_current: 200mA;
}

power GND {
    voltage: 0V;
    type: "reference";
}

module SPI_Bus {
    U1: "SPI_MASTER";
    U2: "SPI_SLAVE";
    U3: "SPI_SLAVE";

    net spi_mosi;
    net spi_miso;
    net spi_sck;
    net cs_dev2;
    net cs_dev3;

    connect U1.VDD  -> power.3V3;
    connect U1.GND  -> power.GND;
    connect U2.VCC  -> power.3V3;
    connect U2.GND  -> power.GND;
    connect U3.VCC  -> power.3V3;
    connect U3.GND  -> power.GND;

    connect U1.MOSI -> spi_mosi;
    connect U2.SDI  -> spi_mosi;
    connect U3.SDI  -> spi_mosi;

    connect U1.MISO -> spi_miso;
    connect U2.SDO  -> spi_miso;
    connect U3.SDO  -> spi_miso;

    connect U1.SCK  -> spi_sck;
    connect U2.CLK  -> spi_sck;
    connect U3.CLK  -> spi_sck;

    connect U1.CS0  -> cs_dev2;
    connect U2.CS   -> cs_dev2;
    connect U1.CS1  -> cs_dev3;
    connect U3.CS   -> cs_dev3;

    routing {
        spi_mosi.impedance: 50Ohm;
        spi_sck.impedance:  50Ohm;
        priority: "length_match";
    }

    validate {
        erc: true;
        drc: true;
    }
}
```

**Note**: U2.SDO and U3.SDO are both `output` on `spi_miso`. This triggers **E303** unless the design uses open-drain MISO (which would be `open_drain` direction). As written, this is a valid HWDL file that produces a **semantic warning E303**. A correct design would use `open_drain` on SDO or add bus arbitration — the DSL faithfully captures the topology and flags the ERC issue.

### 11.3 Valid Example 3 — Power Supply Module with Constraints

```hwdl
hwdl 1.0;

part "LDO_REG" {
    vendor: "TI";
    package: "SOT-223";
    datasheet: "https://www.ti.com/lit/ds/symlink/lm1117.pdf";
    pins {
        VIN:  power_in;
        VOUT: power_out;
        GND:  power_gnd;
        ADJ:  passive;
    }
}

part "GEN_CAP" {
    vendor: "generic";
    package: "0805";
    pins {
        P: passive;
        N: passive;
    }
}

power 5V {
    voltage:     5V;
    tolerance:   5%;
    max_current: 1A;
}

power 3V3 {
    voltage:     3.3V;
    tolerance:   2%;
    max_current: 800mA;
}

power GND {
    voltage: 0V;
    type:    "reference";
}

module LDO_3V3 {
    U1: "LDO_REG";
    C_IN:  "GEN_CAP" { value: 10uF;  voltage_rating: 10V; }
    C_OUT: "GEN_CAP" { value: 100uF; voltage_rating: 6.3V; }

    connect U1.VIN  -> power.5V;
    connect U1.VOUT -> power.3V3;
    connect U1.GND  -> power.GND;
    connect C_IN.P  -> power.5V;
    connect C_IN.N  -> power.GND;
    connect C_OUT.P -> power.3V3;
    connect C_OUT.N -> power.GND;

    constraint {
        dropout_voltage: 1.2V;
        max_output_current: 800mA;
        operating_temp: -20C to 125C;
    }

    placement {
        C_IN.near:  "U1";
        C_OUT.near: "U1";
    }

    validate {
        erc: true;
        footprint_check: true;
    }

    simulate {
        model: "spice";
        dc_op: true;
        step:  10us;
    }
}

target kicad_v6 {
    format: "kicad_v6";
    layers: 2;
}
```

---

### 11.4 Invalid Example 1 — Missing Version Declaration

```hwdl
part "GEN_RES" {
    pins { A: passive; B: passive; }
}
```

**Failure**: `E402 [1:1] version_decl must be the first statement in the file; found keyword "part"`

The parser's first action is to call `parse_version_decl()`. Finding `part` instead of `hwdl` is a hard parse error. No partial IR is emitted.

---

### 11.5 Invalid Example 2 — Three Semantic Errors

```hwdl
hwdl 1.0;

part "MCU" {
    pins {
        VCC: power_in;
        TX:  output;
    }
}

power 3V3 {
    voltage: 3.3V;
    tolerance: 5%;
    max_current: 200mA;
}

power GND {
    voltage: 0V;
    type: "reference";
}

module Bad_Module {
    U1: "MCU";
    U2: "UART_CHIP";    // ERROR E210: part "UART_CHIP" not declared

    net tx_line;
    net tx_line;         // ERROR E206: duplicate net name "tx_line"

    connect U1.VCC -> power.3V3;
    connect U1.TX  -> tx_line;
    connect U1.SDA -> tx_line;  // ERROR E212: pin "SDA" not on part "MCU"
}
```

**Diagnostics** (all reported before aborting):
```
ERROR E210 design.hwdl:22:10
  unknown part "UART_CHIP"; no part declaration found
  in module: Bad_Module

ERROR E206 design.hwdl:25:9
  duplicate net name "tx_line" in module "Bad_Module"; first declared at line 24

ERROR E212 design.hwdl:29:16
  pin "SDA" does not exist on part "MCU" (instance "U1")
  hint: available pins are: VCC, TX
```

---

### 11.6 Invalid Example 3 — Electrical Rules Violations

```hwdl
hwdl 1.0;

part "DRV" {
    pins {
        OUT: output;
        GND: power_gnd;
    }
}

part "RCV" {
    pins {
        IN:  input;
        GND: power_gnd;
    }
}

power 3V3 {
    voltage: 3.3V;
    tolerance: 5%;
    max_current: 100mA;
}

power GND {
    voltage: 0V;
    type: "reference";
}

power SIGNAL_5V {
    voltage: 5V;
    tolerance: 5%;
    max_current: 50mA;
}

module ERC_Fail {
    D1: "DRV";
    D2: "DRV";
    R1: "RCV";

    net shared_out;

    // E300: GND is power_gnd, must connect to 0V domain not signal net
    connect D1.GND -> shared_out;

    // E303: two output pins on same net
    connect D1.OUT -> shared_out;
    connect D2.OUT -> shared_out;

    // E301: power_gnd pin not connected to 0V reference domain
    connect D2.GND -> power.SIGNAL_5V;

    connect R1.IN  -> shared_out;
    connect R1.GND -> power.GND;

    validate {
        erc: true;
    }
}
```

**Diagnostics**:
```
ERROR E300 erc_fail.hwdl:38:5
  pin "D1.GND" has direction "power_gnd" but connected to signal net "shared_out"
  expected a power domain connection

ERROR E301 erc_fail.hwdl:44:5
  pin "D2.GND" has direction "power_gnd"; power domain "SIGNAL_5V" has voltage 5V
  power_gnd pins must connect to a domain with voltage 0V or type "reference"
  hint: did you mean power.GND?

ERROR E303 erc_fail.hwdl:42:5
  net "shared_out" has multiple output pins: D1.OUT, D2.OUT
  only one output driver is allowed per net (use open_drain if bus is required)
```

---

## Appendix A — Pin Direction Semantics

| Direction | Meaning | ERC Rules Applied |
|---|---|---|
| `power_in` | Consumes power from a supply | Must connect to `power_ref`; floating = W021 |
| `power_out` | Provides a regulated supply | At most one per net (E302) |
| `power_gnd` | Ground reference | Must connect to 0V power domain (E301) |
| `input` | Unidirectional signal consumer | No driver check (W020) if net has no output |
| `output` | Unidirectional signal driver | At most one per net (E303) |
| `bidir` | Bidirectional signal | No driver conflict checked |
| `passive` | No defined direction (resistor, cap) | No ERC pin-direction rules |
| `open_drain` | Open-drain output (wired-AND capable) | Multiple allowed per net; no E303 |
| `no_connect` | Intentionally unconnected | Must not appear in `connect` (E304) |

---

## Appendix B — Physical Unit Dimension Table

| Dimension | Units |
|---|---|
| Voltage | `V`, `mV`, `uV` |
| Current | `A`, `mA`, `uA`, `nA` |
| Resistance | `Ohm`, `kOhm`, `MOhm` |
| Capacitance | `F`, `uF`, `nF`, `pF` |
| Inductance | `H`, `mH`, `uH`, `nH` |
| Frequency | `Hz`, `kHz`, `MHz`, `GHz` |
| Power | `W`, `mW` |
| Length | `mm`, `cm`, `um`, `mil` |
| Time | `s`, `ms`, `us`, `ns`, `ps` |
| Temperature | `C` |
| Ratio | `%` |

---

*HWDL Specification v1.0 — End of Document*

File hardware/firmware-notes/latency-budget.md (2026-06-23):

# Pipeline Latency Budget

Target: **< 50 ms** end-to-end from obstacle presence to haptic activation.

---

## Pipeline Stages

```
[Physical obstacle enters camera FOV]
         │
         │ optical propagation (speed of light) → negligible
         ▼
[D435i D435i sensor — depth frame capture]
         │ ~8.3 ms  (at 120 fps, 1/120 s per frame)
         ▼
[USB 3.0 transfer to Pi]
         │ ~1–2 ms  (USB3 latency at 480p depth frame ~60KB)
         ▼
[Depth frame in Pi RAM]
         │
         ▼
[Software: receive frame from librealsense SDK]
         │ ~1–2 ms  (SDK callback, frame already in host memory via DMA)
         ▼
[Depth processing: resize + clip + intensity map]
         │ ~1–2 ms  (NumPy ops on 480×270 → 12×12; CPU-bound)
         ▼
[I2C writes to 9 PCA9685 boards]
         │ ~9 ms    (64 bytes × 9 boards at 400 kHz, sequential)
         ▼
[PCA9685 hardware PWM begins outputting]
         │ < 1 ms  (hardware; no CPU)
         ▼
[MOSFET switches motor current]
         │ < 1 µs  (AO3400A switching time)
         ▼
[ERM motor spins up to tactile threshold]
         │ ~10–20 ms  (ERM rise time; ~15 ms typical for 310-113)
         ▼
[Wearer perceives vibration]
```

---

## Latency Table

| Stage | Time (ms) | Notes |
|---|---|---|
| D435i frame capture | 8.3 | At 120 fps mode; 33 ms at 30 fps |
| USB3 transfer | 1.5 | Measured; D435i SDK uses zero-copy DMA |
| SDK frame delivery | 1.5 | Callback latency |
| Depth resize + map | 2.0 | NumPy on Pi 4 (64-bit, ~1.5 GHz) |
| I2C write all 9 boards | 9.0 | 400 kHz, sequential board writes |
| PCA9685 → MOSFET gate | 0.1 | Hardware PWM |
| MOSFET switching | 0.001 | AO3400A 130 ns transition |
| ERM motor rise time | 15.0 | Mechanical; 10–20 ms typical |
| **Total** | **~37 ms** | Well within 50 ms target |

---

## Operating at 120 fps

The D435i supports the following depth streaming modes:

| Resolution | FPS | Depth latency |
|---|---|---|
| 1280×720 | 30 | 33.3 ms |
| 848×480 | 90 | 11.1 ms |
| 848×480 | 120 | 8.3 ms |
| 640×360 | 90 | 11.1 ms |

For latency optimisation, use **848×480 @ 90 fps**. 120 fps is supported but requires USB bandwidth verification with two simultaneous cameras. At 90 fps, two cameras in depth-only mode (no RGB) stay within the USB3 5 Gbps bandwidth of the Pi's single USB3 hub.

Configure in firmware:

```python
import pyrealsense2 as rs

pipeline = rs.pipeline()
config = rs.config()
config.enable_stream(rs.stream.depth, 848, 480, rs.format.z16, 90)
pipeline.start(config)
```

Disable the RGB stream on both cameras to halve USB bandwidth consumption:

```python
# Do NOT add:
# config.enable_stream(rs.stream.color, ...)
```

---

## I2C Timing Optimisation

Sequential 9-board update (~9 ms) is acceptable. Further optimisations if needed:

### Option 1: PCA9685 ALL_CALL broadcast
- All 9 boards share address 0x70 (ALL_CALL, enabled by default in MODE1 ALLCALL bit)
- A single write to 0x70 updates all 144 channels to the same value simultaneously
- Useful for all-off reset (safety stop in < 1 ms)
- Cannot set individual motor values via ALL_CALL

### Option 2: Parallel I2C buses using Pi I2C_VC (hardware second bus)
- The Pi 4 has a second hardware I2C bus on GPIO0/GPIO1 (I2C0, normally reserved for HAT EEPROM)
- Can be freed with `dtparam=i2c_vc=on`
- Split 9 boards across two buses: 5 on I2C1, 4 on I2C0
- Update both buses concurrently using Python threading
- Reduces I2C write time to ~5 ms

### Option 3: Reduce update resolution
- Only update boards whose motor intensities changed since last frame
- Typical scenario: 3–4 boards near the obstacle are active; others are all-zero
- Skip zero boards with a fast all-channels-off burst (ALL_LED_OFF register write, 4 bytes)
- Can reduce average I2C time to ~3 ms

---

## ERM Rise Time

The 310-113 ERM has a typical rise time (0→63% rated amplitude) of ~15 ms. This is mechanical and cannot be shortened in software. However:

- **Preemptive activation**: activate motors at low intensity (~10% duty cycle) when obstacles are detected at > 2 m range. This keeps the motor spinning slightly, reducing rise time to full intensity to ~5 ms when the obstacle enters the danger zone.
- This "standby spin" pattern only activates motors in cells that have any obstacle closer than 5 m, at < 5% duty cycle — below perception threshold for most users.

With preemptive activation, effective onset latency can be reduced to **~25 ms total**.

---

## Worst-Case Latency Analysis

Worst case (two cameras simultaneously produce large depth frames, I2C bus has retries):

| Stage | Worst-case time (ms) |
|---|---|
| Frame capture (90 fps) | 11.1 |
| USB3 + SDK | 5.0 |
| Processing | 4.0 |
| I2C writes (with one retry per board) | 18.0 |
| ERM rise | 20.0 |
| **Total worst-case** | **~58 ms** |

Worst case slightly exceeds 50 ms due to ERM mechanical delay. The 50 ms target is met for the electrical + computational path (≤ 38 ms worst case). Adding preemptive motor spin eliminates the ERM rise contribution and achieves < 40 ms reliably.

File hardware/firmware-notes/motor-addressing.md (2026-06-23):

# Motor Addressing — PCA9685 Channel to Motor Index Mapping

## Addressing Scheme

Motor numbers are 0-based (0–143) in software. The physical grid is row-major, left-to-right, top-to-bottom:

```
Motor index = row * 12 + col    (row 0–11, col 0–11)
```

Each PCA9685 board controls 16 consecutive motors:

```
Board n (0-indexed) controls motors: n*16  to  n*16 + 15
```

To resolve a motor index to an I2C address and channel:

```python
I2C_ADDRESSES = [0x40, 0x41, 0x42, 0x43, 0x44, 0x45, 0x46, 0x47, 0x48]

def motor_to_pca(motor_idx: int) -> tuple[int, int]:
    """
    Returns (i2c_address, channel_0_to_15) for a given motor index (0-based).
    Raises ValueError if motor_idx is out of range.
    """
    if not 0 <= motor_idx <= 143:
        raise ValueError(f"motor_idx {motor_idx} out of range 0–143")
    board = motor_idx // 16
    channel = motor_idx % 16
    return I2C_ADDRESSES[board], channel

def grid_to_motor(row: int, col: int) -> int:
    """
    Converts (row, col) 0-based grid coordinates to a motor index 0–143.
    """
    if not (0 <= row <= 11 and 0 <= col <= 11):
        raise ValueError(f"grid position ({row},{col}) out of range")
    return row * 12 + col
```

---

## PCA9685 Register Write for One Motor

The PCA9685 controls motor intensity via PWM duty cycle. Each channel has four registers:
`LED_n_ON_L`, `LED_n_ON_H`, `LED_n_OFF_L`, `LED_n_OFF_H`.

For a motor that turns ON at counter=0 and OFF at `duty` (0–4095):

```
LED_n_ON_L  = 0x00
LED_n_ON_H  = 0x00
LED_n_OFF_L = duty & 0xFF
LED_n_OFF_H = (duty >> 8) & 0x0F
```

The register base address for channel n is `0x06 + 4*n`.

Full single-motor write (Python, using smbus2):

```python
import smbus2

bus = smbus2.SMBus(1)

def set_motor(bus, motor_idx: int, intensity: int) -> None:
    """
    intensity: 0 (off) to 4095 (full on)
    """
    addr, ch = motor_to_pca(motor_idx)
    reg_base = 0x06 + 4 * ch
    duty = max(0, min(4095, intensity))
    data = [0x00, 0x00, duty & 0xFF, (duty >> 8) & 0x0F]
    bus.write_i2c_block_data(addr, reg_base, data)
```

---

## Bulk Update — All 144 Motors in One Pass

For a full heatmap update, group writes by board to minimise I2C transactions.

Each PCA9685 supports auto-increment (AI bit in MODE1 = 1). Writing 64 bytes starting at register 0x06 updates all 16 channels in one transaction:

```python
def update_board(bus, board_idx: int, intensities: list[int]) -> None:
    """
    board_idx: 0–8
    intensities: list of 16 values, each 0–4095
    """
    assert len(intensities) == 16
    addr = I2C_ADDRESSES[board_idx]
    data = []
    for duty in intensities:
        duty = max(0, min(4095, duty))
        data += [0x00, 0x00, duty & 0xFF, (duty >> 8) & 0x0F]
    # Write 64 bytes starting at LED0_ON_L (0x06), auto-increment handles the rest
    bus.write_i2c_block_data(addr, 0x06, data)

def update_all_motors(bus, heatmap: list[int]) -> None:
    """
    heatmap: flat list of 144 intensity values (0–4095), row-major
    """
    assert len(heatmap) == 144
    for board_idx in range(9):
        start = board_idx * 16
        update_board(bus, board_idx, heatmap[start:start + 16])
```

Typical time for one full update: ~9 ms at 400 kHz I2C. See `latency-budget.md`.

---

## Depth-to-Intensity Mapping

Raw depth from RealSense D435i is in millimetres (uint16). Map to motor intensity:

```python
import numpy as np

MIN_DIST_MM = 300     # closer than this → max intensity
MAX_DIST_MM = 3000    # farther than this → off

def depth_frame_to_heatmap(depth_frame_mm: np.ndarray) -> list[int]:
    """
    depth_frame_mm: H×W uint16 array of depth values in mm
    Returns: flat list of 144 intensity values (0–4095)
    """
    # Resize to 12×12
    import cv2
    resized = cv2.resize(
        depth_frame_mm.astype(np.float32),
        (12, 12),
        interpolation=cv2.INTER_AREA
    )

    # Clamp distances
    resized = np.clip(resized, MIN_DIST_MM, MAX_DIST_MM)

    # Inverse mapping: closer → higher intensity
    # Use a nonlinear curve (inverse square) for better perceptual resolution at close range
    normalized = (MAX_DIST_MM - resized) / (MAX_DIST_MM - MIN_DIST_MM)
    intensity = (normalized ** 2) * 4095

    return intensity.flatten().astype(int).tolist()
```

When using two cameras (front chest, different tilt angles), fuse their heatmaps by taking the element-wise minimum depth (nearest obstacle in each cell wins) before mapping to intensity.

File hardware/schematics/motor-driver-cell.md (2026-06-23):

# Single Motor Driver Cell

This circuit is repeated 144 times — once per ERM motor.

```
PCA9685 PWM Output Pin (3.3V logic, open-drain with pull-up)
                │
               [R] 220Ω  (RC0402FR-07220RL)
                │
                └──────────────── Gate (AO3400A)
                                       │
                         ┌─────────────┤
                         │         AO3400A (SOT-23)
                         │             │
                    Source ────────── GND (0V)
                                       │
                                   Drain ──────────── Motor negative terminal (–)
                                                              │
                                                         [ERM Motor]
                                                    Precision Microdrives 310-113
                                                              │
                                              Motor positive terminal (+) ──── 3V rail
                                                              │
                                         [Flyback diode: 1N4148WS, SOD-323]
                                          Cathode → 3V rail
                                          Anode   → Motor negative (= MOSFET Drain)
```

---

## Schematic in Table Form

| Node | Component | Connection |
|---|---|---|
| PWM_n | PCA9685 channel n output | → 220Ω gate resistor |
| Gate | AO3400A G | ← 220Ω from PWM_n |
| Source | AO3400A S | → GND |
| Drain | AO3400A D | → Motor − terminal; Diode anode |
| Motor + | ERM + | → 3V rail |
| Motor − | ERM − | → AO3400A Drain |
| D_anode | 1N4148WS A | → AO3400A Drain (= Motor −) |
| D_cathode | 1N4148WS K | → 3V rail |

---

## Design Rationale

### 220Ω Gate Resistor

Without a gate resistor, the parasitic capacitance at the gate (Ciss ≈ 270 pF for AO3400A) combined with the very low output impedance of the PCA9685 creates a high dV/dt at turn-on. This causes:
- Excessive current spike in the driver
- High-frequency ringing on the gate, potentially causing spurious oscillations

220Ω limits peak gate current to ≈ 3.3 V / 220 Ω = 15 mA, which is well within the PCA9685 source/sink rating of 25 mA. Switching time is still fast (τ = 220 × 270 pF = 59 ns → 10–90% transition in ~130 ns), acceptable for a 200 Hz PWM signal.

### Flyback Diode Placement

The diode must be placed physically as close to the motor terminals as possible — on the motor PCB pad or at the JST-SH connector. If placed at the PCA9685 board instead, the wiring inductance between the diode and the motor adds extra voltage spike. Aim for < 10 mm lead length from diode to motor terminals.

### N-Channel Low-Side Switch

The motor is switched on the low side (between motor − and GND). This means:
- Gate drive is simple: Vgs = logic voltage (3.3 V), no bootstrap required
- Motor + terminal is always tied to the 3V rail (no shoot-through risk)
- Ground is shared between logic and motor rails (important: keep 3V motor GND and 5V logic GND tied at one star point to prevent ground offset)

---

## PWM Duty Cycle to Haptic Intensity

The PCA9685 generates 12-bit PWM (0–4095 steps). The motor responds roughly linearly in amplitude to RMS voltage up to ~3 V.

| Duty cycle | Effective Vrms | Relative intensity |
|---|---|---|
| 0% | 0 V | Off |
| 25% | 1.5 V | ~25% — barely perceptible |
| 50% | 2.1 V | ~55% — clearly felt |
| 75% | 2.6 V | ~80% — strong |
| 100% | 3.0 V | 100% — maximum |

Software should map depth sensor distance to a duty cycle using a nonlinear (e.g., inverse-square or log-inverse) curve so that the haptic sensation changes gradually at long distances and sharply at close range.

---

## PCB Layout Notes for Production

When moving from perfboard to a custom PCB:

1. Place the MOSFET and its flyback diode together in a cell. Repeat the cell 16 times per driver board (one per PCA9685 board).
2. Motor current traces must carry 80 mA sustained, 140 mA peak (stall). A 0.15 mm trace width on 1 oz copper is sufficient (ampacity ~400 mA), but use 0.3 mm for margin.
3. 3V motor power plane on the bottom layer, logic signals on the top layer. Separate pour fills with a 0.5 mm gap.
4. One 100 µF electrolytic + one 100 nF ceramic cap per PCA9685 board on the 5V supply.
5. One 100 nF ceramic cap per MOSFET drain (motor supply side) to absorb fast transients.

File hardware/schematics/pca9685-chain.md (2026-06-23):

# PCA9685 I2C Chain — Wiring and Addressing

## Physical Chain Topology

All nine PCA9685 boards share a single I2C bus in parallel (not daisy-chained serially). Each board is independently addressable.

```
Raspberry Pi GPIO2 (SDA) ─────┬───────┬───────┬─── ... ─── PCA9 SDA
                               │       │       │
Raspberry Pi GPIO3 (SCL) ─────┼───┬───┼───┬───┼─── ... ─── PCA9 SCL
                               │   │   │   │   │
                              PCA1 │  PCA2 │  PCA3
                              SDA  │  SDA  │  SDA
                              SCL  │  SCL  │  SCL

Each board also receives:
  5V  → PCA9685 VCC
  GND → PCA9685 GND
  3.3V → PCA9685 V3V3 (logic reference for output drivers)

Pull-ups:
  SDA: 4.7kΩ to 3.3V (one resistor at Pi end, in addition to Pi internal ~1.8kΩ)
  SCL: 4.7kΩ to 3.3V (one resistor at Pi end, in addition to Pi internal ~1.8kΩ)
```

Use a JST-XH 4-pin (5V / GND / SDA / SCL) connector between each board for cleanly removable connections. The chain uses the same connector footprint on all nine boards; individual cables plug directly from a small distribution hub (a 4-pin screw terminal or bus bar on the vest frame).

---

## Address Configuration

The PCA9685 base address is 0x40. Pins A0–A5 are all pulled low by default (open-drain with no solder bridge = 0).

| Board | I2C Address | A5 | A4 | A3 | A2 | A1 | A0 |
|---|---|---|---|---|---|---|---|
| PCA1 | 0x40 | 0 | 0 | 0 | 0 | 0 | 0 |
| PCA2 | 0x41 | 0 | 0 | 0 | 0 | 0 | 1 |
| PCA3 | 0x42 | 0 | 0 | 0 | 0 | 1 | 0 |
| PCA4 | 0x43 | 0 | 0 | 0 | 0 | 1 | 1 |
| PCA5 | 0x44 | 0 | 0 | 0 | 1 | 0 | 0 |
| PCA6 | 0x45 | 0 | 0 | 0 | 1 | 0 | 1 |
| PCA7 | 0x46 | 0 | 0 | 0 | 1 | 1 | 0 |
| PCA8 | 0x47 | 0 | 0 | 0 | 1 | 1 | 1 |
| PCA9 | 0x48 | 0 | 0 | 1 | 0 | 0 | 0 |

On Adafruit #815 boards, address bits are set by bridging the solder pads labelled A0–A5 on the underside. A bridged pad = 1. Leave unbridged = 0. Bridge with a small blob of solder.

---

## I2C Bus Speed

Use 400 kHz (fast-mode). The Pi's I2C peripheral supports this natively.

Set in `/boot/config.txt`:
```
dtparam=i2c_arm=on,i2c_arm_baudrate=400000
```

Or via `raspi-config` → Interface Options → I2C → enable.

At 400 kHz, updating all 144 channels requires:

- Per channel: 1 address byte + 1 register byte + 4 data bytes (LED_ON_L, LED_ON_H, LED_OFF_L, LED_OFF_H) = 6 bytes
- Per PCA9685: 16 channels × 6 bytes = 96 bytes, plus start/stop framing ≈ 100 bytes total per board
- Nine boards: 900 bytes
- At 400 kHz, 1 bit ≈ 2.5 µs: 900 × 8 × 2.5 µs = 18 ms

**This is too slow for 50 ms target if done naively.** Use the PCA9685 ALL_CALL feature to broadcast to all boards simultaneously if all channels get the same value (e.g., all-off reset), and batch writes using auto-increment mode. For individual per-motor updates, use the smbus2 `write_i2c_block_data` call to write all 64 bytes per board in one transaction:

- Per board in one transaction: ~1 ms at 400 kHz
- Nine boards sequentially: ~9 ms
- Total I2C update budget: ~9 ms — well within 50 ms target

See `firmware-notes/latency-budget.md` for full pipeline timing.

---

## PCA9685 Initialization Sequence

For each board (pseudocode):

```python
# 1. Enter SLEEP mode to allow PRE_SCALE write
write_byte(addr, MODE1, 0x10)       # SLEEP=1, ALLCALL=0

# 2. Set PWM frequency to ~200 Hz
# PRE_SCALE = round(25_000_000 / (4096 × freq)) - 1
write_byte(addr, PRE_SCALE, 0x1E)   # 0x1E = 30 → ≈196.9 Hz

# 3. Wake up; enable auto-increment
write_byte(addr, MODE1, 0xA0)       # SLEEP=0, AI=1, ALLCALL=0

# 4. Wait 500 µs oscillator stabilisation
time.sleep(0.0005)

# 5. Set all channels to 0 (motors off)
write_byte(addr, ALL_LED_ON_L,  0x00)
write_byte(addr, ALL_LED_ON_H,  0x00)
write_byte(addr, ALL_LED_OFF_L, 0x00)
write_byte(addr, ALL_LED_OFF_H, 0x10)  # 0x1000 = full OFF
```

Register addresses (from PCA9685 datasheet):

| Register | Address |
|---|---|
| MODE1 | 0x00 |
| MODE2 | 0x01 |
| LED0_ON_L | 0x06 |
| LED0_ON_H | 0x07 |
| LED0_OFF_L | 0x08 |
| LED0_OFF_H | 0x09 |
| ALL_LED_ON_L | 0xFA |
| ALL_LED_ON_H | 0xFB |
| ALL_LED_OFF_L | 0xFC |
| ALL_LED_OFF_H | 0xFD |
| PRE_SCALE | 0xFE |

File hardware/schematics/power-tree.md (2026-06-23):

# Power Distribution Tree

```
USB-C Power Bank (65W PD, ≥20,000 mAh)
        │
        │ USB-C cable (5A rated, 20V PD negotiated)
        ▼
 PD Trigger Board (C2PD) + 20V→5V buck
 Input:  20V PD (up to 3.25A / 65W available)
 Output: 5V / 8A = 40W (covers ~31W system peak ≈ 6.3A)
        │
        │ 5V / 8A bus
        ├──────────────────────────────────────────────────────────────┐
        │                                                              │
        ▼                                                              ▼
 Raspberry Pi 4B (5V / 1.2A typ, 2A max)            Buck Converter (5V → 3.0V / 5A)
        │                                             MP1584EN module
        │ 3.3V onboard LDO (max 3A)                          │
        ├───────────────────────────────────┐                │ 3.0V motor rail
        │                                   │                │
        ▼                                   ▼                ▼
 GPIO/I2C outputs (PCA9685 VCC 5V)    PCA9685 V3V3     MOSFET drains → ERM motors ×144
 I2S outputs (MAX98357A VIN 5V)       (gate drive ref)
        │                                                    │
        ▼                                                    ▼
 USB3 ports ×2                                   Flyback diodes → 3.0V rail (return)
        │
        ├── D435i camera #1 (5V / 300mA = 1.5W)
        └── D435i camera #2 (5V / 300mA = 1.5W)
```

---

## Fusing and Protection

| Rail | Fuse Rating | Type | Location |
|---|---|---|---|
| 5V main bus | 8A | Polyfuse (PPTC) | At PD board output |
| 3V motor rail | 5A | Polyfuse (PPTC) | At buck converter output |
| Pi 5V input | Protected by Pi board | — | Pi has internal protection |

Use a blade-style automotive fuse holder or an 8A-hold PTC resettable fuse (e.g., Bourns MF-R800) in series with the 5V line before the Pi.

---

## Power Budget — Detailed

### Raspberry Pi 4B

| State | Current | Power |
|---|---|---|
| Idle (desktop off) | 540 mA | 2.7 W |
| Active (camera processing, I2C writes) | 1,200 mA | 6.0 W |
| Peak (brief CPU spike) | 1,800 mA | 9.0 W |

Sustained design value: **6 W @ 5V**

### D435i Cameras (×2)

| State | Current each | Power each |
|---|---|---|
| Idle | 190 mA | 0.95 W |
| Streaming depth + RGB | 300 mA | 1.50 W |

Two cameras: **3 W @ 5V**

### PCA9685 Boards (×9)

| State | Current per board | Power per board |
|---|---|---|
| Idle | 5 mA | 0.025 W |
| All channels active | 10 mA | 0.050 W |

Nine boards: **< 0.5 W @ 5V** (negligible)

### ERM Motors (×144)

| Metric | Value |
|---|---|
| Rated voltage | 3.0 V |
| Rated current per motor | 80 mA |
| Stall current per motor | 140 mA |
| Power per motor @ rated | 0.24 W |
| All 144 @ rated | 34.6 W |
| All 144 @ 100% duty cycle | 34.6 W peak |

**Realistic average**: Depth-proximity haptic patterns activate roughly 30% of motors at any time, and average duty cycle is ~50%.

```
Average motor power = 144 × 0.30 × 0.50 × 0.24 W = 5.2 W
Peak motor power (close obstacle, high intensity) ≈ 144 × 0.60 × 0.80 × 0.24 W = 16.6 W
```

Design for 20% headroom: **20 W motor rail budget @ 3V**, requiring **~21 W from 5V bus** (buck efficiency ~95%).

### MAX98357A + Speaker

| State | Power |
|---|---|
| Idle / quiet | 0.1 W |
| Speech output (typical) | 1.0 W |
| Maximum output (3.2W into 4Ω, but speaker is 8Ω) | 1.6 W |

Design value: **1 W @ 5V**

---

## Total Power Budget Summary

| Consumer | Average (W) | Peak (W) |
|---|---|---|
| Raspberry Pi 4 | 6.0 | 9.0 |
| D435i ×2 | 3.0 | 3.0 |
| ERM motors ×144 | 5.2 | 16.6 |
| Audio | 1.0 | 1.6 |
| PCA9685 ×9 | 0.5 | 0.5 |
| **Total** | **15.7 W** | **30.7 W** |

### Battery Life Estimate

```
Bank capacity: 26,800 mAh × 3.7V (nominal Li-ion) = 99 Wh
Usable (85% efficiency): ~84 Wh
At 15.7W average: 84 / 15.7 = 5.4 hours
At 30.7W peak (continuous): 84 / 30.7 = 2.7 hours
```

Practical expectation: **4–5 hours per charge** under normal active use.

---

## Ground Plane Notes

All grounds (5V logic GND, 3V motor GND, speaker GND) must connect at **one star point** — the ground terminal of the PD trigger board output. Do not create separate ground islands that connect only through cable runs; this creates ground loops and motor switching noise on I2C signals.

The buck converter's GND pin must connect to this same star point, not to the motor frame.

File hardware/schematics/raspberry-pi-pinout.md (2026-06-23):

# Raspberry Pi 4B GPIO Pin Assignments

## Physical Pin Header (40-pin, BCM numbering)

```
                    3V3  1 ●│● 2  5V
    I2C SDA   GPIO2  3 ●│● 4  5V
    I2C SCL   GPIO3  5 ●│● 6  GND ◄── I2C chain GND, PCA9685 GND
              GPIO4  7 ○│○ 8  GPIO14 (TXD)
                   GND  9 ●│○ 10 GPIO15 (RXD)
             GPIO17 11 ○│○ 12 GPIO18 ◄── I2S BCLK (MAX98357A)
             GPIO27 13 ○│● 14 GND
             GPIO22 15 ○│○ 16 GPIO23
                3V3 17 ○│○ 18 GPIO24
    SPI MOSI GPIO10 19 ○│● 20 GND
    SPI MISO  GPIO9 21 ○│○ 22 GPIO25
    SPI SCLK GPIO11 23 ○│○ 24 GPIO8 (CE0)
                   GND 25 ○│○ 26 GPIO7 (CE1)
              GPIO0 27 ○│○ 28 GPIO1
              GPIO5 29 ○│○ 30 GND
              GPIO6 31 ○│○ 32 GPIO12
             GPIO13 33 ○│● 34 GND
I2S LRCLK  GPIO19 35 ●│○ 36 GPIO16
             GPIO26 37 ○│○ 38 GPIO20
                   GND 39 ○│● 40 GPIO21 (I2S DIN → MAX98357A)

● = used    ○ = available
```

---

## Pin Assignment Table

| BCM GPIO | Physical Pin | Signal | Destination | Notes |
|---|---|---|---|---|
| GPIO2 | 3 | I2C1 SDA | PCA9685 boards ×9 SDA | Hardware I2C; add 4.7kΩ pull-up to 3.3V |
| GPIO3 | 5 | I2C1 SCL | PCA9685 boards ×9 SCL | Hardware I2C; add 4.7kΩ pull-up to 3.3V |
| GPIO18 | 12 | I2S BCLK | MAX98357A BCLK | Hardware I2S audio |
| GPIO19 | 35 | I2S LRCLK / PCM_FS | MAX98357A LRCLK | Also labelled PCM_FS in some schematics |
| GPIO21 | 40 | I2S DIN / PCM_DOUT | MAX98357A DIN | Data out from Pi to amp |
| — | 1 | 3.3V | PCA9685 V3V3 (×9) | Also pull-up reference for I2C resistors |
| — | 4 | 5V | PCA9685 VCC (×9), MAX98357A VIN | 5V logic rail |
| — | 6,9,14,20,25,30,34,39 | GND | All ground references | Star ground back to PD board |

---

## MAX98357A Wiring Detail

| MAX98357A Pin | Pi Physical Pin | Signal | Notes |
|---|---|---|---|
| BCLK | Pin 12 | GPIO18 (I2S CLK) | Bit clock |
| LRC / LRCLK | Pin 35 | GPIO19 (I2S LRCLK) | Word select / frame clock |
| DIN | Pin 40 | GPIO21 (I2S DOUT) | Audio data from Pi to amp |
| GND | Pin 6 | GND | |
| VIN | Pin 4 | 5V | |
| SD (shutdown) | — | Leave floating | Float = normal operation; pull low to mute |
| GAIN | — | Leave floating | Float = 9 dB gain |

Speaker + and − connect to MAX98357A output terminals (labelled OUT+ / OUT− on Adafruit board). Polarity does not matter for a single speaker.

---

## Camera Connections

Both D435i cameras connect to **USB 3.0 Type-A** ports on the Pi 4B (the blue ports). The Pi 4B has two USB 3.0 ports, which exactly matches two cameras.

No GPIO wiring required for cameras.

---

## I2C Bus Enable

Enable I2C on the Pi before first use:

```bash
sudo raspi-config
# → Interface Options → I2C → Yes

# Or directly:
sudo sh -c 'echo "dtparam=i2c_arm=on,i2c_arm_baudrate=400000" >> /boot/config.txt'
sudo reboot

# Verify devices detected:
sudo i2cdetect -y 1
```

Expected output (9 PCA9685 boards):

```
     0  1  2  3  4  5  6  7  8  9  a  b  c  d  e  f
00:                         -- -- -- -- -- -- -- -- --
10: -- -- -- -- -- -- -- -- -- -- -- -- -- -- -- -- --
20: -- -- -- -- -- -- -- -- -- -- -- -- -- -- -- -- --
30: -- -- -- -- -- -- -- -- -- -- -- -- -- -- -- -- --
40: 40 41 42 43 44 45 46 47 48 -- -- -- -- -- -- -- --
50: -- -- -- -- -- -- -- -- -- -- -- -- -- -- -- -- --
60: -- -- -- -- -- -- -- -- -- -- -- -- -- -- -- -- --
70: -- -- -- -- -- -- -- 70                          --
```

0x70 is the PCA9685 ALL_CALL address (broadcast to all boards). This is expected.

---

## I2S Audio Enable

Enable I2S overlay:

```bash
sudo sh -c 'echo "dtoverlay=hifiberry-dac" >> /boot/config.txt'
sudo reboot

# Verify audio device:
aplay -l
# Should list: card 0: sndrpihifiberry [snd_rpi_hifiberry_dac]
```

Set playback volume:

```bash
alsamixer -c 0
# or
amixer -c 0 set Digital 80%
```

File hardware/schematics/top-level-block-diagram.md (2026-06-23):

# Top-Level System Block Diagram

```
                          ┌─────────────────────────────────┐
                          │   USB-C PD Power Bank            │
                          │   65W / ≥20,000mAh               │
                          └──────────────┬──────────────────┘
                                         │ USB-C PD (20V)
                                         │
                               ┌─────────▼──────────┐
                               │  PD Trigger Board  │
                               │  (C2PD or equiv.)  │
                               │  20V → 5V / 8A     │
                               └────────┬───────────┘
                                        │ 5V rail
                          ┌─────────────┴──────────────┐
                          │                            │
               ┌──────────▼───────────┐   ┌───────────▼──────────┐
               │   Raspberry Pi 4B    │   │   Buck Converter      │
               │   4GB RAM            │   │   5V → 3.0V / 5A      │
               │   5V / 1.2A          │   │   MP1584EN module     │
               └──┬────┬────┬────┬───┘   └───────────┬──────────┘
                  │    │    │    │                     │ 3V motor rail
                  │    │    │    │                     │
                USB3  USB3  I2C  I2S                  Motor
                  │    │    │    │                   Supply Bus
                  │    │    │    │                     │
          ┌───────▼┐  ┌▼───┐│   │             ┌───────┴────────────────────────┐
          │D435i #1│  │D435││   │             │  MOSFET Driver Array (×144)    │
          │Front   │  │ #2 ││   │             │  AO3400A + 220Ω + 1N4148WS     │
          │Upper   │  │Frt ││   │             │  (see motor-driver-cell.md)    │
          │+35°    │  │0°  ││   │             └───────────────────────────────┘
          └────────┘  └────┘│   │                         ▲
                             │   │                         │ PWM gate signals
                             │   │               ┌─────────┴──────────────────────┐
                             │   │               │  PCA9685 Chain (×9)            │
                             │   │               │  I2C addresses 0x40–0x48       │
                             │   │               │  16 ch each = 144 ch total     │
                             │   │               └────────────────────────────────┘
                             │   │                         ▲
                             │   │                         │ I2C (SDA/SCL)
                             │   └─────────────────────────┘
                             │   I2C bus (400 kHz fast-mode)
                             │
                             │ I2S (BCLK/LRCLK/DIN)
                  ┌──────────▼──────────┐
                  │   MAX98357A         │
                  │   I2S Class D Amp   │
                  │   3.2W max          │
                  └──────────┬──────────┘
                             │ Speaker output
                  ┌──────────▼──────────┐
                  │   8Ω 3W Speaker     │
                  │   Shoulder mount    │
                  └─────────────────────┘
```

---

## Signal Flow Summary

```
Depth frames (D435i ×2)
        │
        ▼ USB3 (~11 ms: capture + transfer + SDK delivery)
Raspberry Pi 4 — depth processing (~2 ms)
        │
        ▼ I2C writes to PCA9685 chain (~9 ms for 144 ch update)
PCA9685 × 9 — PWM generation (hardware; zero CPU overhead)
        │
        ▼ Gate drive via 220Ω
AO3400A × 144 — switch motor current
        │
        ▼ 3V / 80mA per motor (ERM rise ~15 ms)
ERM Motor × 144 — vibrotactile output
```

Total pipeline ~37 ms obstacle→perception; see `firmware-notes/latency-budget.md`.

---

## Voltage Rails Summary

| Rail | Source | Consumers | Notes |
|---|---|---|---|
| 5 V logic | PD trigger board | Pi, PCA9685 VCC, MAX98357A | Fused at 8 A |
| 3.3 V | Pi onboard LDO | PCA9685 V3V3, gate signals | Pi provides; do not load >200 mA externally |
| 3.0 V motor | Buck converter | 144 ERM motors via MOSFETs | Separate rail; keeps noise off logic |
| USB 5 V | Pi USB ports | D435i ×2 (each 1.5 W) | Pi's USB3 ports supply cameras |

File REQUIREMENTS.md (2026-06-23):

# VisionPilot Architecture & Requirements

## Overview
VisionPilot is an Android application that functions as a smart, accessible mobile agent. It allows users to execute voice commands that control their device securely via Accessibility Services, the Android MediaProjection API, and an external Agent Backend.

The architecture is divided into two primary parts:
1. **The Android Client (VisionPilot):** An aggressive, standalone Kotlin-based service framework utilizing Jetpack Compose, Room DB, Audio Capture, Screen Capture (MediaProjection), and UI Hierarchy extraction (AccessibilityService).
2. **The Agent Backend (WebSocket Server):** A server acting as the intelligence layer, processing screenshots, UI layout data, and user queries to determine the next immediate UI interaction.

This document serves as the guide for anyone looking to set up the corresponding backend capable of interpreting the VisionPilot payloads.

---

## The Android Client Data Flow
When a user issues a command (e.g., "Open YouTube and search for cats"):
1. The `AgentActionExecutor` initiates a 10-step event loop.
2. At every step:
   - The `ScreenCaptureService` grabs a compressed Base64 JPEG of the screen.
   - The `VisionPilotAccessibilityService` structures the current UI tree into a JSON array, mapping `className`, `label`, `center_x`, and `center_y`.
   - The command, screenshot, and UI tree are pushed over WebSocket to the URL configured in `WebSocketManager` (`ws://agent/connect`).
3. The Backend responds with a discrete `AgentAction` JSON payload telling the Android client what to do next.

---

## Backend Requirements
To successfully run the AI model backend that talks to VisionPilot, you need a WebSocket-capable server (tested typically with Python/FastAPI) and an LLM capable of Vision and JSON reasoning (e.g., Gemini 1.5 Pro).

### `requirements.txt`
The included `requirements.txt` file contains the Python dependencies needed to build the server:
- **FastAPI / Uvicorn:** For WebSocket hosting.
- **WebSockets / Pydantic:** For data modeling and socket handling.
- **Google Generative AI:** To pass the bounding boxes, screenshot, and command into the Gemini model.
- **Pillow:** For image parsing if you intend to draw debug overlays server-side.

### Expected Payload from Android -> Backend
The client sends payload requests in this standard JSON format:
```json
{
  "session_id": "c4d7e2-45a8-...",
  "command": "call mom",
  "screenshot": "<base64_jpeg_string>",
  "package_name": "com.android.launcher",
  "ui_tree": [
    {
      "index": 0,
      "role": "android.widget.TextView",
      "label": "Messages",
      "center_x": 450,
      "center_y": 1200
    }
  ]
}
```

### Expected Payload from Backend -> Android
The backend must evaluate the screenshot, the tree, and the goal, then select a single action to reply with. The reply must map perfectly to the Android `AgentAction` class structure:

```json
{
  "type": "tap", 
  "x": 450, 
  "y": 1200,
  "text": "Messages",
  "packageId": null,
  "contactName": null,
  "message": null
}
```

### Actions Supported by `AgentActionExecutor.kt`
- `"tap"`: Clicks at `{x, y}` or uses `text` to find the node.
- `"type"`: Types `text` into the currently focused or clicked input field.
- `"scroll"`: Triggers `ACTION_SCROLL_FORWARD` or backward.
- `"back"`: Uses `GLOBAL_ACTION_BACK`.
- `"home"`: Uses `GLOBAL_ACTION_HOME`.
- `"launch_app"`: Requires `packageId`. Uses Android's `PackageManager` to boot the app.
- `"call"`: Requires `contactName` or `text`. Uses `ContactsContract` resolving, then opens `tel:` intent.
- `"whatsapp"`: Requires `contactName` and optionally `message`. Resolves contact and fires the `wa.me/` Intent URL.
- `"speak"`: Uses the in-app TTS engine to read `message` to the user.
- `"done"`: The loop is finished successfully. `message` provides summary.
- `"error"`: Abort the loop if stuck or failed.

## Environment Variables Needed for Backend
```env
GEMINI_API_KEY="AIzaSy..."
PORT=8000
HOST="0.0.0.0"
```

## Testing Protocol
1. Start the Python API with `uvicorn main:app --host 0.0.0.0 --port 8000`
2. Make sure your Android device / emulator shares the same network.
3. In Android `WebSocketManager.kt`, change `WS_URL = "ws://agent/connect"` to `ws://YOUR_LOCAL_IP:8000/connect` (e.g., `ws://192.168.1.100:8000/connect`).
4. Rebuild the Android app. 
5. Start dictation or type a command. The AgentLoop will spin up, passing data to Python and reacting to your AI's responses.

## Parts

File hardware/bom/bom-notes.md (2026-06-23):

# BOM Notes — Sourcing, Substitutions, Tolerances

## AO3400A MOSFET

The AO3400A is logic-level compatible. The PCA9685 outputs 3.3 V PWM from a 3.3 V VCC pin. The AO3400A datasheet shows:

- Vgs(th) max = 1.45 V
- Id = 4 A continuous at Tc = 70 °C
- Rds(on) = 56 mΩ at Vgs = 2.5 V
- SOT-23 package

At Vgs = 3.3 V the device is fully enhanced. At 80 mA motor current the Vds drop is negligible (< 5 mV). No level shifter required.

**Acceptable substitutes:** IRLML2502 (same SOT-23, similar Vgs(th)), 2N7002 (lower current but fine for 80 mA). Do not substitute with logic-level parts that need ≥ 4 V gate drive.

---

## Flyback Diode

The 1N4148WS (SOD-323) has a reverse recovery time of 4 ns, which is fast enough to clamp the inductive kick when the MOSFET turns off. The motor inductance is low (typical ERM coil ~100 µH) but the clamping diode must be placed physically close to the motor terminals.

**Acceptable substitute:** BAT54 (Schottky, even faster, lower Vf). Do not use 1N4007 — its reverse recovery is too slow (30 µs) and it will not protect the MOSFET adequately at PWM frequencies above a few kHz.

---

## PCA9685

The PCA9685 has a configurable I2C address via six address pins (A0–A5), giving 64 possible addresses. We use nine boards at 0x40–0x48, which requires setting:

| Board | A0 | A1 | A2 | A3 | A4 | A5 |
|---|---|---|---|---|---|---|
| PCA1 (0x40) | 0 | 0 | 0 | 0 | 0 | 0 |
| PCA2 (0x41) | 1 | 0 | 0 | 0 | 0 | 0 |
| PCA3 (0x42) | 0 | 1 | 0 | 0 | 0 | 0 |
| PCA4 (0x43) | 1 | 1 | 0 | 0 | 0 | 0 |
| PCA5 (0x44) | 0 | 0 | 1 | 0 | 0 | 0 |
| PCA6 (0x45) | 1 | 0 | 1 | 0 | 0 | 0 |
| PCA7 (0x46) | 0 | 1 | 1 | 0 | 0 | 0 |
| PCA8 (0x47) | 1 | 1 | 1 | 0 | 0 | 0 |
| PCA9 (0x48) | 0 | 0 | 0 | 1 | 0 | 0 |

On Adafruit-style boards, these are solder jumpers (bridge with solder). On bare PCA9685 ICs, pull address pins to VCC (1) or leave floating/GND (0) per the datasheet.

The PCA9685 internal oscillator is 25 MHz with ±1% accuracy. For ERM motor PWM (target ~200 Hz), set the PRE_SCALE register to match. The exact PRE_SCALE value for 200 Hz:

```
PRE_SCALE = round(25_000_000 / (4096 × 200)) - 1 = round(30.52) - 1 = 30
```

Write 0x1E to register 0xFE of each board. Do this while the SLEEP bit in MODE1 is set.

---

## ERM Motor — Precision Microdrives 310-113

Key specs:

| Parameter | Value |
|---|---|
| Diameter | 10 mm |
| Thickness | 2.7 mm |
| Rated voltage | 3 V |
| Rated current | 80 mA |
| No-load current | 45 mA |
| Stall current | 140 mA |
| Start voltage | 1.5 V |
| Operating range | 1.5 – 3.5 V |
| Amplitude @ 3V | ~2.0 G |
| Frequency @ 3V | ~200 Hz |

The 310-113 has a 0.8 mm shaft with a flat. Ensure the adhesive pad (included or sourced separately) faces the vest fabric side, not the electronics side.

**Substitutes:** Any 10 mm coin ERM running at 3 V and drawing ≤ 120 mA. Larger motors (e.g., 12 mm) will not fit at 35 mm center-to-center spacing in a 12×12 grid.

---

## Power Bank Requirements

The power bank must support USB-C Power Delivery (PD) and sustain at least ~35 W on a single port (the system peaks at ~31 W, negotiated at 20 V). Many banks advertise 65 W but cannot sustain that continuously from a single port.

Verified models (as of 2025):
- Anker 737 Power Bank (PowerCore 26K) — dual 140 W ports, 25 600 mAh
- UGREEN 25000mAh 130W — sustained 65 W per port confirmed
- Baseus Blade 100W — thinner form factor

The PD trigger board (C2PD or similar, with a 20 V→5 V buck stage) negotiates 20 V from the bank and steps down to 5 V / 8 A cleanly (40 W output, covering the ~31 W / ~6.3 A system peak). A bare 5 V / 5 A (25 W) trigger is undersized. Do not try to power the system directly from a 5 V USB-A port — the current limit is too low.

---

## 3 V Motor Rail

The Pi's 5V rail must not power the motors directly. Use a dedicated buck converter (MP1584EN, MINI560-5V variant with output trimmed down, or a pre-built module). Set output to exactly 3.00 V using a multimeter before connecting motors.

Max continuous output required: 144 motors × 30% active × 80 mA = 3.5 A. Use a converter rated ≥ 5 A for thermal margin.

---

## I2C Pull-Up Resistors

The Pi's GPIO2/GPIO3 (SDA/SCL) have internal 1.8 kΩ pull-ups already enabled in the Pi's I2C peripheral. With nine PCA9685 boards on the bus, the total capacitive load is ~90 pF. At 400 kHz (fast-mode I2C) the RC time constant is:

```
τ = 1800 × 90×10⁻¹² = 162 ns
```

The I2C spec requires edges within 300 ns — this is marginal. Add external 4.7 kΩ pull-ups to 3.3 V on the SDA and SCL lines (in parallel with the Pi's internal ones), bringing effective pull-up to ~1.3 kΩ. This comfortably meets the 300 ns rise time spec.

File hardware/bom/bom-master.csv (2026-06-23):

Reference | Description | Manufacturer | MPN | Qty | Unit Price USD (est.) | Extended USD (est.) | Digikey PN | Mouser PN | Notes
U1 | Raspberry Pi 4 Model B 4GB | Raspberry Pi Foundation | SC0194 | 1 | 55.00 | 55.00 | 2648-SC0194-ND |  | Official board; 4 GB required for RealSense workload
CAM1-CAM2 | Intel RealSense Depth Camera D435i | Intel | 82635AWG | 2 | 199.00 | 398.00 |  |  | USB 3.2 Gen 1; includes factory IMU
PWM1-PWM9 | PCA9685 16-Ch 12-bit I2C PWM/Servo Driver Board | NXP (Adafruit breakout) | PCA9685 | 9 | 7.95 | 71.55 |  |  | Adafruit #815 or equivalent; solder address jumpers
Q1-Q144 | N-Channel MOSFET 30V 4A SOT-23 | AOS | AO3400A | 144 | 0.12 | 17.28 | AO3400A-ND | 863-AO3400A | Vgs(th) max 1.45V; logic-level gate drive from PCA9685 OK
D1-D144 | Fast-Switching Rectifier Diode SOD-323 | Vishay | 1N4148WS-7-F | 144 | 0.03 | 4.32 | 1N4148WS-FDICT-ND | 78-1N4148WS-7-F | Flyback protection across motor; 75V 150mA
M1-M144 | Coin Vibration Motor 10mm 3V ERM | Precision Microdrives | 310-113 | 144 | 2.50 | 360.00 |  |  | 3V 80mA typ; 12000 RPM; 2g amplitude; 0.95g centrifugal
R1-R144 | Resistor 220Ω 0402 1/16W 1% | Yageo | RC0402FR-07220RL | 144 | 0.01 | 1.44 | 311-220LRCT-ND | 652-RC0402FR-07220RL | Gate series resistor; limits dV/dt and short-circuit current
U2 | I2S Audio Amplifier Breakout MAX98357A | Maxim (Adafruit breakout) | MAX98357AEWL | 1 | 5.95 | 5.95 |  |  | Adafruit #3006; I2S input; 3.2W into 4Ω
SP1 | Speaker 8Ω 3W 40mm Round | CUI Devices | CMS-40038-L152 | 1 | 3.50 | 3.50 | CMS-40038-L152-ND |  | Shoulder-mount; rated 3W continuous
J1-J9 | JST-XH 4-Pin Right-Angle Through-Hole Header | JST | B4B-XH-A | 9 | 0.35 | 3.15 | 455-2249-ND | 538-B4B-XH-A | I2C chain daisy-chain; 5V/GND/SDA/SCL
J10-J153 | JST-SH 2-Pin Horizontal SMD Header | JST | SM02B-SRSS-TB | 144 | 0.28 | 40.32 | 455-1793-ND | 538-SM02B-SRSS-TB | Motor harness; +/- per motor
CABLE1-CABLE2 | USB 3.2 Gen1 Type-A to Type-A 1m | Belkin or equiv |  | 2 | 5.00 | 10.00 |  |  | D435i to Pi USB3 port
CABLE3 | USB-C PD Trigger + 20V→5V 8A Buck Module (PD decoy) | Witrn or equiv | C2PD-8A | 1 | 11.00 | 11.00 |  |  | Negotiates 20V PD then bucks to 5V/8A (40W); must cover ~31W (≈6.3A) system peak — a bare 5V/5A trigger is undersized
REG1 | DC-DC Buck Converter 5V→3V 5A | MINI560 or MP1584 module |  | 1 | 3.50 | 3.50 |  |  | 3V motor rail; adjustable; set output with trim pot
CAP1-CAP9 | Electrolytic Capacitor 100µF 16V | Panasonic | EEU-FM1C101 | 9 | 0.18 | 1.62 | P15381CT-ND | 667-EEU-FM1C101 | Bulk decoupling per PCA9685 board VCC
CAP10-CAP153 | Ceramic Capacitor 100nF 0402 50V | Yageo | CC0402KRX5R9BB104 | 144 | 0.02 | 2.88 | 311-1266-1-ND | 603-CC0402KRX5R9BB104 | Local decoupling per MOSFET drain-side
BANK1 | Power Bank 65W USB-C PD 26800mAh | Anker 737 or UGREEN 25000 |  | 1 | 89.99 | 89.99 |  |  | 65W PD output; ≥20000mAh; two USB-C ports preferred
PCB1 | Custom MOSFET driver PCB (or perf board for proto) |  |  |  |  |  |  |  | See motor-driver-cell.md for schematic
VEST1 | Tactical vest or compression vest base |  |  |  | 1 | 30.00 | 30.00 |  |  | Rigid enough to hold motors in a flat 12×12 grid
MISC | Hook-and-loop fastener strip 1m | 3M or Velcro |  | 1 | 5.00 | 5.00 |  |  | Motor retention on vest fabric
MISC2 | 28AWG silicone wire assorted colors 10m |  |  | 1 | 12.00 | 12.00 |  |  | Motor harness wiring; silicone rated for flex
MISC3 | JST-SH pre-crimped wire pairs 15cm |  |  | 144 | 0.15 | 21.60 |  |  | Motor pigtails; saves crimping time
 | TOTAL (estimated BOM) |  |  |  |  |  | ~1148.00 |  | Excludes PCB fabrication tooling and shipping

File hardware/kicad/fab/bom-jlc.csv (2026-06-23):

Comment | Designator | Footprint | LCSC Part # | Manufacturer | MPN | Qty | Unit Price USD (est.) | Description
PCA9685PW | U1 | Package_SO:TSSOP-28_4.4x9.7mm_P0.65mm | C9067 | NXP | PCA9685PW | 1 | 1.50 | 16-channel 12-bit I2C PWM/Servo controller TSSOP-28
AO3400A | Q1,Q2,Q3,Q4,Q5,Q6,Q7,Q8,Q9,Q10,Q11,Q12,Q13,Q14,Q15,Q16 | Package_TO_SOT_SMD:SOT-23 | C20917 | AOS | AO3400A | 16 | 0.08 | 30V 4A N-Channel MOSFET Vgs(th)max=1.45V SOT-23
220R | R1,R2,R3,R4,R5,R6,R7,R8,R9,R10,R11,R12,R13,R14,R15,R16 | Resistor_SMD:R_0402_1005Metric | C25091 | Yageo | RC0402FR-07220RL | 16 | 0.01 | 220 Ohm 1% 1/16W 0402 gate series resistor
1N4148WS | D1,D2,D3,D4,D5,D6,D7,D8,D9,D10,D11,D12,D13,D14,D15,D16 | Diode_SMD:D_SOD-323 | C57759 | Vishay | 1N4148WS-7-F | 16 | 0.02 | Fast switching diode 75V 150mA SOD-323 flyback protection
100nF | C3,C4,C5,C6,C7,C8,C9,C10,C11,C12,C13,C14,C15,C16,C17,C18 | Capacitor_SMD:C_0402_1005Metric | C49678 | Yageo | CC0402KRX5R9BB104 | 16 | 0.01 | 100nF 50V X5R 0402 local drain bypass capacitor
100nF | C2 | Capacitor_SMD:C_0402_1005Metric | C49678 | Yageo | CC0402KRX5R9BB104 | 1 | 0.01 | 100nF 50V X5R 0402 PCA9685 VCC bypass

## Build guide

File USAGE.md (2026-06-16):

# How to Use the Agent

  Samvit's AI hardware pipeline lives in the `agent/` package. Here's everything you need to get started.

  ---

  ## Prerequisites

  - Python 3.10+
  - A Gemini API key (free tier works for testing)

  Install dependencies:

  ```bash
  pip install -r requirements.txt
  ```

  Set your environment variables:

  ```bash
  export GEMINI_API_KEY_1="your-key-here"
  # Optional — helps with quota limits
  export GEMINI_API_KEY_2="your-second-key-here"
  ```

  ---

  ## Running the Pipeline

  ### Quick demo (built-in example)

  ```bash
  python main.py --demo
  ```

  This runs the full pipeline on a built-in haptic feedback wearable example — no input file needed.

  ---

  ### From a plain-text description

  Describe what you want to build in natural language:

  ```bash
  python main.py "Build a wearable haptic feedback glove for the visually impaired"
  ```

  ---

  ### From a structured JSON requirements file

  Create a `requirements.json` file:

  ```json
  {
    "name": "My Device",
    "description": "A wrist-worn device that...",
    "goals": [
      "Detect obstacles at 0.5–5m range",
      "Vibration feedback via haptic motors",
      "BLE connectivity to companion app",
      "8+ hours battery life"
    ]
  }
  ```

  Then run:

  ```bash
  python main.py --req requirements.json
  ```

  ---

  ### With a human override file

  Override specific pipeline decisions manually:

  ```bash
  python main.py "..." --overrides human_overrides.json
  ```

  ---

  ## Environment Variables

  | Variable | Required | Default | Description |
  |---|---|---|---|
  | `GEMINI_API_KEY_1` | ✅ Yes | — | Primary Gemini API key |
  | `GEMINI_API_KEY_2` | No | — | Secondary key for quota relief |
  | `SAMVIT_DB_PATH` | No | `hardware_builder/samvit_parts.db` | Path to the component database |
  | `SAMVIT_CHECKPOINT` | No | `checkpoint/` | Directory for saving pipeline checkpoints |
  | `SAMVIT_MAX_ITER` | No | `8` | Maximum main loop iterations |

  ---

  ## What the Pipeline Does

  When you run the pipeline, it:

  1. **Parses requirements** — understands your hardware goals
  2. **Plans architecture** — decides MCU, sensors, power strategy
  3. **Fetches datasheets** — pulls real component datasheets
  4. **Searches component DB** — finds matching parts in the database
  5. **Selects parts** — picks the best components for your use case
  6. **Checks compatibility** — validates voltage, pinout, and BOM conflicts
  7. **Generates schematic** — produces a circuit graph
  8. **Runs layout stages** — footprint mapping, placement, routing
  9. **Runs design checks** — ERC, DRC, power, thermal, short-circuit analysis
  10. **Simulates** — runs SPICE-style simulation
  11. **Exports** — outputs KiCad files, Gerbers, JSONL logs, ASCII visualizer

  ---

  ## Output Files

  After a successful run you'll find:

  ```
  checkpoint/          ← Intermediate pipeline state (auto-saved)
  output/              ← Final exports (KiCad, Gerber, reports)
  ```

  ---

  ## Package Structure

  ```
  agent/
  ├── __init__.py
  ├── orchestrator.py         ← Top-level pipeline runner
  ├── core/
  │   ├── models.py           ← Shared data models (DesignState, etc.)
  │   ├── checkpoint.py       ← Save/load pipeline state
  │   └── gemini_manager.py   ← Gemini API key rotation & calls
  └── pipeline/
      ├── p01_requirements.py ← Stage 1: parse requirements
      ├── p03_architecture.py ← Stage 3: plan architecture
      ├── p05_datasheet.py    ← Stage 5: fetch datasheets
      ├── ...                 ← (30 pipeline stages total)
      └── p30_human_override.py
  ```

  ---

  ## Troubleshooting

  **`ModuleNotFoundError: No module named 'agent'`**
  Make sure you're running from the repo root:
  ```bash
  cd /path/to/samvit
  python main.py --demo
  ```

  **Gemini quota errors**
  Set a second API key via `GEMINI_API_KEY_2`. The pipeline rotates between keys automatically.

  **Pipeline stalls on a stage**
  Increase the iteration limit:
  ```bash
  SAMVIT_MAX_ITER=16 python main.py --demo
  ```

  ---

  ## Contributing

  1. Fork the repo
  2. Create a feature branch: `git checkout -b my-feature`
  3. Add your stage(s) in `agent/pipeline/` following the existing naming pattern
  4. Open a PR — describe what your stage does and which pipeline step it fits into

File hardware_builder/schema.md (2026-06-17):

# Samvit — Hardware Spec

## What You're Building

A body-worn device that takes in live depth data from two sensors, builds a spatial heatmap of the environment, and communicates it to the user through a 144-motor vibration grid and audio tones — replacing vision for navigation in real time.

---

## Sensors

**Use: Intel RealSense D435i (x2)**
- One forward-facing, one angled upward ~30°
- Forward sensor covers ground to chest height
- Angled sensor covers chest to top of user's head
- Both connect via USB to the processing unit
- Python library: `pyrealsense2` — gives depth frames directly, well documented, widely used

---

## Processing Unit

**Use: Raspberry Pi 4 (4GB)**
- Runs Python natively
- Has enough USB ports for both RealSense sensors
- Supports PWM control, I2C, and WiFi all on one board
- This is where the heatmap processing and all signal logic runs
- No additional compute needed

---

## Vibration Grid (144 Motors)

**Motors: ERM (Eccentric Rotating Mass) coin vibration motors**
- Small, flat, lightweight — suitable for body-worn use
- Arranged in a 12×12 grid worn on the torso (front or vest-style)
- The grid maps directly to the heatmap — each motor corresponds to a zone in the user's environment
- Closer obstacle = stronger vibration in that motor's position on the grid

**Driver: PCA9685 PWM Driver boards (x9, chained via I2C)**
- Each PCA9685 drives 16 motors
- 9 boards chained together = 144 motors
- All controlled over a single I2C connection from the Raspberry Pi
- Python library: `adafruit-circuitpython-pca9685` — lets you set any motor's intensity in one line

---

## Audio Output

**Use: Any small speaker via MAX98357A I2S amplifier**
- Handles directional audio tones for destination guidance
- Connects directly to Raspberry Pi GPIO
- Python library: `sounddevice` — generate and play tones programmatically in real time

---

## Communication with Software Layer

**Use: Raspberry Pi's built-in WiFi**
- The Jarvis voice AI sends destination coordinates over local WiFi to the Pi
- No extra hardware needed — Pi handles this natively
- On the software side, a simple socket connection receives the coordinates

---

## What the Hardware Designer Does Not Need to Worry About

- How the heatmap is computed (software side)
- How destination coordinates are generated (voice AI side)
- Audio content or tone logic (software side)

The designer's job is: sensors feed into the Pi, Pi drives the motor grid and speaker. Everything else is software.

---

## Success Bar

- Full 144-motor grid responds to environment in under 50ms
- Both sensor zones (lower + upper) detected and mapped independently
- User can distinguish obstacle direction and height from vibration position alone
- Device runs for 4+ hours on battery

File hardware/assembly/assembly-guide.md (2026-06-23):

# Assembly Guide

Follow this sequence exactly. Each step assumes the previous one is complete and verified.

---

## Tools Required

- Soldering iron + solder (63/37, 0.6 mm)
- Hot air station (for SOD-323 diodes and SOT-23 MOSFETs if building on PCB)
- Multimeter (voltage and continuity)
- JST-SH crimping tool (PA-09 or Engineer PA-21)
- Small diagonal cutters and wire strippers
- 3D-printed 35 mm spacing template (optional but recommended)
- Fabric marker
- Double-sided foam tape (3M VHB 1 mm)

---

## Step 1 — Prepare the Vest

1. Lay the vest flat on a work surface, back panel facing up.
2. Locate the center of the back panel (width and height midpoint).
3. Mark the 12×12 grid with a fabric marker:
   - Start 17.5 mm from the intended grid edges (half a motor pitch)
   - Columns spaced 35 mm apart
   - Rows spaced 35 mm apart
   - Total 144 intersection points
4. Verify the outer grid bounds fit within the vest back panel dimensions.
5. Stitch 5 mm × 50 mm hook-and-loop strips in horizontal runs at every row for cable routing.

---

## Step 2 — Attach Motors

1. Cut 144 squares of 3M VHB double-sided foam tape, approximately 7 mm × 7 mm.
2. Peel one side; apply to the back (non-vibrating) face of each motor.
3. For each intersection point on the grid:
   - Peel the second foam tape face
   - Press the motor flat on the mark, vibrating mass facing the vest fabric
   - Apply firm pressure for 30 seconds
4. Label each motor M001–M144 with a small adhesive label on the motor body before attachment (easier to trace faults later).
5. Run motor pigtail wires along the nearest horizontal cable route, secured with hook-and-loop.

---

## Step 3 — Build MOSFET Driver Boards

For prototype: use 9 separate perfboard panels, one per PCA9685 group (16 driver cells each).

For each of the 16 driver cells per board:

1. Install AO3400A MOSFET in SOT-23 orientation (Gate=pin1, Source=pin3, Drain=pin2).
2. Install 220Ω resistor (0402) between PCA9685 channel output pad and MOSFET gate.
3. Install 1N4148WS diode (SOD-323) across motor pads — cathode (+) toward 3V rail, anode (−) toward MOSFET drain.
4. Install 100nF ceramic capacitor between MOSFET drain pad and 3V rail (local supply decoupling).
5. Install JST-SH 2-pin header for motor connection.
6. Install JST-XH 4-pin header for I2C + power input from Pi chain.

Verify continuity (no short between 3V rail and GND) before proceeding.

---

## Step 4 — Install PCA9685 Boards

1. Set address solder jumpers on each PCA9685 board per the addressing table in `schematics/pca9685-chain.md`.
2. Verify each board's I2C address with a continuity meter across the address jumpers.
3. Mount the 9 PCA9685 boards in the vest's rear electronics pocket or on a rigid backing plate.
4. Connect the JST-XH 4-pin I2C/power cable from the Pi distribution hub to each board.
5. Add one 100µF electrolytic capacitor across VCC–GND on each PCA9685 board (solder across the power rails).

---

## Step 5 — Mount Raspberry Pi

1. Mount the Pi in its rear enclosure (3D-printed or ABS box) on the lower back section of the vest.
2. Secure with M2.5 standoffs and screws.
3. Connect I2C distribution hub to Pi GPIO pins 3 (SDA) and 5 (SCL), plus 3.3V (pin 1) and GND (pin 6).
4. Solder 4.7kΩ pull-up resistors from SDA to 3.3V and SCL to 3.3V at the Pi header.
5. Connect MAX98357A audio amp to Pi GPIO18/19/21 and 5V/GND per pinout table.
6. Route USB-C power cable from power bank to PD trigger board.
7. Route PD board 5V output to Pi USB-C input and to 5V bus bar.

---

## Step 6 — Connect RealSense Cameras

1. Mount camera #1 (upper, +35° tilt) on the front chest strap, top position.
   - Use a 3D-printed bracket angled at 35° downward from horizontal.
   - Fasten bracket to MOLLE webbing with a 25 mm strap.
2. Mount camera #2 (lower, 0° / horizontal) on the front chest strap, lower position, ~150 mm below camera #1.
3. Route USB3 cables from both cameras over the shoulder to the Pi USB3 (blue) ports.
4. Use cable clips every 150 mm along the vest strap to secure the cables.
5. Do not strain-relieve the USB connector with tape — use proper cable hooks to allow connector removal.

Camera placement rationale:
- Upper camera at +35° captures ground plane from ~1.5 m range at eye level when standing
- Lower camera at 0° captures obstacles at chest height; combined FOV covers roughly ground to head height within 3 m

---

## Step 7 — Install Audio

1. Mount MAX98357A board inside the electronics pocket, secured with foam tape.
2. Connect speaker wire (26 AWG, ~500 mm) from MAX98357A OUT+/OUT− to shoulder-mounted speaker.
3. Mount speaker in a 3D-printed housing on the shoulder strap with M2 screws.
4. Route speaker wire under the shoulder padding.

---

## Step 8 — Power Rail Verification

Before enabling motors:

1. Measure voltage at 5V bus bar with multimeter: should read 4.95–5.05 V.
2. Measure voltage at 3V motor rail output with multimeter: trim buck converter until it reads 3.00–3.05 V. Do this **before** connecting motors.
3. Verify GND continuity between Pi GND pin, 5V bus bar GND, and 3V rail GND (all should be 0Ω).
4. Verify no short between 5V bus and GND, and between 3V motor rail and GND.
5. With motors disconnected, enable power and re-measure all rails under logic load (Pi + PCA9685 boards powered).
6. Connect motor harnesses only after all rails are verified.

---

## Step 9 — Software Setup and First Boot

1. Flash Raspberry Pi OS Lite (64-bit) to a microSD card.
2. Enable I2C and I2S in `/boot/config.txt` (see `schematics/raspberry-pi-pinout.md`).
3. Install dependencies:
   ```bash
   sudo apt-get update
   sudo apt-get install -y python3-smbus2 python3-pip librealsense2-dev
   pip3 install pyrealsense2 adafruit-circuitpython-pca9685
   ```
4. Run `i2cdetect -y 1` and verify all 9 PCA9685 addresses appear (0x40–0x48).
5. Proceed to validation tests in `tests/validation-procedures.md`.

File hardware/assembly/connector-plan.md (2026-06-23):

# Connector Plan

## I2C Bus Chain — JST-XH 4-Pin

Used between the Raspberry Pi I2C breakout header and each PCA9685 board.

| Pin | Signal | Wire Color (suggested) |
|---|---|---|
| 1 | 5V | Red |
| 2 | GND | Black |
| 3 | SDA | White |
| 4 | SCL | Yellow |

**Connector:** JST-XH B4B-XH-A (board-side header) + XHP-4 (housing) + SXH-001T-P0.6 (crimp terminal)

**Mating cable length:** 150–200 mm between boards, routed under the vest liner. Use the same 4-pin JST-XH cable to daisy-chain from a small bus distribution PCB (or terminal block strip) mounted at the center of the vest.

Recommended distribution approach: one JST-XH 4-pin bus bar (a small breakout with one input and 9 outputs) fed from the Pi header. This avoids a daisy-chain where removing one board breaks the downstream chain.

---

## Motor Harness — JST-SH 2-Pin

Used between the MOSFET driver board output and each ERM motor.

| Pin | Signal | Wire Color |
|---|---|---|
| 1 | Motor + (3V) | Red |
| 2 | Motor − (MOSFET Drain) | Black |

**Connector:** JST-SH SM02B-SRSS-TB (board-side SMD header) + SHR-02V-S (housing) + SSH-003T-P0.2 (crimp terminal)

**Cable:** 28 AWG silicone-insulated wire, 100–150 mm length. Pre-crimped pigtail pairs (JST-SH 2-pin, 150 mm) are available from Adafruit (#4046) and save significant assembly time — strongly recommended.

**Motor lead:** The Precision Microdrives 310-113 ships with 50 mm wire leads with tinned ends. Solder these directly to the JST-SH female housing pins (no crimping needed at the motor end), then heat-shrink the solder joint.

---

## Power Rail — Ring/Fork Terminals on Bus Bar

The 5V rail and 3V motor rail run as bus bars along the vest frame (a rigid PCB strip or copper foil tape).

| Connection | Terminal | Gauge |
|---|---|---|
| PD board → 5V bus bar | M3 ring terminal | 20 AWG |
| Buck converter output → 3V bus bar | M3 ring terminal | 20 AWG |
| PCA9685 VCC taps from 5V bar | JST-XH (shared with I2C cable) | 24 AWG |
| MOSFET 3V supply taps from 3V bar | 0.1" pin header, 2-pin | 24 AWG |

---

## Camera USB Cables

The Intel RealSense D435i ships with a USB 3.2 Gen1 Type-A to Type-C cable (1 m). Use the factory cable. If a replacement is needed:

- Must be USB 3.2 Gen 1 (5 Gbps) rated
- Length: 0.5–1.0 m (longer cables increase susceptibility to bandwidth issues)
- Connector: Type-A (Pi) to Type-C (camera)
- Do not use USB 2.0 cables — the D435i depth stream requires USB 3 bandwidth

Secure cable runs along the vest shoulder straps with cable clips or hook-and-loop ties to prevent snagging.

---

## Audio — MAX98357A to Pi and Speaker

| Signal | Connection |
|---|---|
| Pi GPIO18 → BCLK | 3-pin 0.1" dupont header (female) or direct solder |
| Pi GPIO19 → LRCLK | same |
| Pi GPIO21 → DIN | same |
| Pi 5V → VIN | same |
| Pi GND → GND | same |
| Speaker + → OUT+ | 2-pin screw terminal on MAX98357A board |
| Speaker − → OUT− | 2-pin screw terminal on MAX98357A board |

Speaker cable: 26 AWG, 500 mm (shoulder to chest mount). Use a 2-pin JST-PH connector at the speaker for removability.

---

## Main Power Input

| Connection | Details |
|---|---|
| Power bank → PD trigger board | USB-C 5A rated cable, 200 mm |
| PD board output → Pi 5V input | USB-C to USB-C, or bare wire to Pi GPIO header pins 2,4 (5V) and 6 (GND) |
| PD board output → 5V bus bar | Direct solder + ring terminal |

If powering the Pi via GPIO pins 2/4 and 6 (instead of the USB-C port): note that this bypasses the Pi's onboard polyfuse. This is acceptable if you have a polyfuse on the 5V bus bar itself. GPIO 5V pins are rated for 5A per the Pi 4 schematic.

---

## Connector Summary Table

| Interface | Connector Family | Board-side | Cable-side | Qty |
|---|---|---|---|---|
| I2C bus to each PCA9685 | JST-XH 4-pin | B4B-XH-A | XHP-4 + pigtail | 9 |
| Motor harness | JST-SH 2-pin | SM02B-SRSS-TB | SHR-02V-S + 150mm | 144 |
| Speaker | JST-PH 2-pin | S2B-PH-K-S | PHR-2 + pigtail | 1 |
| Power rail taps (5V) | JST-XH (shared with I2C) | — | — | — |
| USB cameras | USB-A to USB-C | — | Factory cable | 2 |
| Main power | USB-C | — | 5A cable | 1 |

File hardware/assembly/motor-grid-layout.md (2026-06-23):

# Motor Grid Layout — 12 × 12

## Physical Grid on Vest

The 144 motors are arranged in a 12-column × 12-row grid across the back of the vest.

```
Column:  C01  C02  C03  C04  C05  C06  C07  C08  C09  C10  C11  C12
        ┌────┬────┬────┬────┬────┬────┬────┬────┬────┬────┬────┬────┐
Row 01  │ 01 │ 02 │ 03 │ 04 │ 05 │ 06 │ 07 │ 08 │ 09 │ 10 │ 11 │ 12 │
        ├────┼────┼────┼────┼────┼────┼────┼────┼────┼────┼────┼────┤
Row 02  │ 13 │ 14 │ 15 │ 16 │ 17 │ 18 │ 19 │ 20 │ 21 │ 22 │ 23 │ 24 │
        ├────┼────┼────┼────┼────┼────┼────┼────┼────┼────┼────┼────┤
Row 03  │ 25 │ 26 │ 27 │ 28 │ 29 │ 30 │ 31 │ 32 │ 33 │ 34 │ 35 │ 36 │
        ├────┼────┼────┼────┼────┼────┼────┼────┼────┼────┼────┼────┤
Row 04  │ 37 │ 38 │ 39 │ 40 │ 41 │ 42 │ 43 │ 44 │ 45 │ 46 │ 47 │ 48 │
        ├────┼────┼────┼────┼────┼────┼────┼────┼────┼────┼────┼────┤
Row 05  │ 49 │ 50 │ 51 │ 52 │ 53 │ 54 │ 55 │ 56 │ 57 │ 58 │ 59 │ 60 │
        ├────┼────┼────┼────┼────┼────┼────┼────┼────┼────┼────┼────┤
Row 06  │ 61 │ 62 │ 63 │ 64 │ 65 │ 66 │ 67 │ 68 │ 69 │ 70 │ 71 │ 72 │
        ├────┼────┼────┼────┼────┼────┼────┼────┼────┼────┼────┼────┤
Row 07  │ 73 │ 74 │ 75 │ 76 │ 77 │ 78 │ 79 │ 80 │ 81 │ 82 │ 83 │ 84 │
        ├────┼────┼────┼────┼────┼────┼────┼────┼────┼────┼────┼────┤
Row 08  │ 85 │ 86 │ 87 │ 88 │ 89 │ 90 │ 91 │ 92 │ 93 │ 94 │ 95 │ 96 │
        ├────┼────┼────┼────┼────┼────┼────┼────┼────┼────┼────┼────┤
Row 09  │ 97 │ 98 │ 99 │100 │101 │102 │103 │104 │105 │106 │107 │108 │
        ├────┼────┼────┼────┼────┼────┼────┼────┼────┼────┼────┼────┤
Row 10  │109 │110 │111 │112 │113 │114 │115 │116 │117 │118 │119 │120 │
        ├────┼────┼────┼────┼────┼────┼────┼────┼────┼────┼────┼────┤
Row 11  │121 │122 │123 │124 │125 │126 │127 │128 │129 │130 │131 │132 │
        ├────┼────┼────┼────┼────┼────┼────┼────┼────┼────┼────┼────┤
Row 12  │133 │134 │135 │136 │137 │138 │139 │140 │141 │142 │143 │144 │
        └────┴────┴────┴────┴────┴────┴────┴────┴────┴────┴────┴────┘
```

Motor index formula:

```python
motor_index = (row - 1) * 12 + (col - 1)   # 0-based
# or
motor_number = row * 12 - (12 - col)         # 1-based (M001–M144)
```

---

## Physical Dimensions

| Parameter | Value |
|---|---|
| Center-to-center spacing | 35 mm |
| Grid width (11 gaps × 35 mm) | 385 mm |
| Grid height (11 gaps × 35 mm) | 385 mm |
| Motor diameter | 10 mm |
| Gap between motor edges | 25 mm |
| Total panel area | ~420 mm × 420 mm including edge margins |

The 420 mm × 420 mm panel fits within the back panel of most tactical/plate-carrier vests (typical back panel: 250–300 mm wide × 350 mm tall). **Reduce to a 10×10 grid (100 motors) or reduce spacing to 28 mm if the vest back is smaller than 400 mm in either dimension.** Measure the vest before committing to spacing.

---

## PCA9685 Board-to-Motor Assignment

Each PCA9685 board controls 16 consecutive motors in row-major order.

| PCA Board | I2C Addr | Motors (1-based) | Grid Rows |
|---|---|---|---|
| PCA1 | 0x40 | M001 – M016 | Row 1, Row 2 cols 1–4 |
| PCA2 | 0x41 | M017 – M032 | Row 2 cols 5–12, Row 3 cols 1–8 |
| PCA3 | 0x42 | M033 – M048 | Row 3 cols 9–12, Row 4 |
| PCA4 | 0x43 | M049 – M064 | Row 5, Row 6 cols 1–4 |
| PCA5 | 0x44 | M065 – M080 | Row 6 cols 5–12, Row 7 cols 1–8 |
| PCA6 | 0x45 | M081 – M096 | Row 7 cols 9–12, Row 8 |
| PCA7 | 0x46 | M097 – M112 | Row 9, Row 10 cols 1–4 |
| PCA8 | 0x47 | M113 – M128 | Row 10 cols 5–12, Row 11 cols 1–8 |
| PCA9 | 0x48 | M129 – M144 | Row 11 cols 9–12, Row 12 |

Software mapping (Python):

```python
PCA_ADDR = [0x40, 0x41, 0x42, 0x43, 0x44, 0x45, 0x46, 0x47, 0x48]

def motor_to_pca(motor_idx: int) -> tuple[int, int]:
    """
    motor_idx: 0-based (0–143)
    Returns (i2c_address, channel) where channel is 0–15.
    """
    board = motor_idx // 16
    channel = motor_idx % 16
    return PCA_ADDR[board], channel
```

---

## Vest Orientation Convention

- Row 1 = **top** of back panel (near shoulders)
- Row 12 = **bottom** of back panel (near lumbar)
- Column 1 = **left** side (wearer's left)
- Column 12 = **right** side (wearer's right)

The depth camera heatmap is projected onto this grid with the same orientation: upper-left of the camera depth image maps to M001 (top-left of vest), lower-right maps to M144 (bottom-right of vest).

---

## Motor Attachment Method

Recommended: double-sided foam tape (3M VHB 1.0 mm, 5 mm × 5 mm squares cut to size) on the back face of the motor. The vibrating mass is on the underside facing the vest fabric, ensuring vibration is transmitted into the vest and to the skin.

Do not glue directly — motors fail and need replacement. Use hook-and-loop (Velcro) loops stitched to the vest fabric for final retention of harness cable runs, with the foam tape holding the motor head itself.

Mark the 12×12 grid on the vest panel with a fabric marker and a 35 mm spacing template (a 3D-printed jig simplifies this) before attaching motors.

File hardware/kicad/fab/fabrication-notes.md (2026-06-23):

# Fabrication Notes — Motor Driver 16-Channel Board

## Board Identification

| Field | Value |
|---|---|
| Board name | Haptic Vest 16-Ch Motor Driver |
| File | `motor-driver-16ch.kicad_pcb` |
| Revision | 1.0 |
| Date | 2026-06-18 |
| Dimensions | 100.0 mm × 70.0 mm |
| Board count (prototype run) | 9 (one per PCA9685 group) |

---

## JLC PCB Order Form — Fill These In Exactly

Navigate to jlcpcb.com → Quote Now → upload the Gerber ZIP from `fab/gerbers/`.

| Parameter | Value | Notes |
|---|---|---|
| **Base Material** | FR-4 | Standard |
| **Layers** | 2 | F.Cu + B.Cu |
| **Dimensions** | 100 mm × 70 mm | Auto-detected from Gerber |
| **PCB Qty** | 10 (minimum order) | Order 10, use 9 |
| **Different Design** | 1 | |
| **Delivery Format** | Single PCB | |
| **PCB Thickness** | 1.6 mm | Standard |
| **PCB Color** | Black | Better contrast for silkscreen labels |
| **Silkscreen** | White | |
| **Surface Finish** | HASL (with lead)  | Cheapest; ENIG (+$5) if preferred for fine-pitch TSSOP-28 pads |
| **Outer Copper Weight** | 1 oz | Standard |
| **Via Covering** | Tented | |
| **Board Outline Tolerance** | ±0.2 mm | |
| **Confirm Production File** | Yes | Review before production |
| **Remove Order Number** | Yes (+$1.50) | Avoids silkscreen number on board |
| **Flying Probe Test** | Yes (included) | |
| **Gold Fingers** | No | |
| **Castellated Holes** | No | |
| **Edge Plating** | No | |

**Recommended finish for TSSOP-28 at 0.65mm pitch:** ENIG (Electroless Nickel Immersion Gold) gives flat, solderable pads that are much easier to hand-solder than HASL which leaves uneven bumps. The $5 upcharge per board is worth it for the 9 boards needed.

---

## JLC SMT Assembly (Optional — Saves Manual Soldering)

If ordering SMT assembly for the SMD components (strongly recommended for the 0402 resistors/caps and SOD-323 diodes):

1. Upload `fab/gerbers/` ZIP as before
2. Enable "SMT Assembly" toggle
3. Upload `fab/bom-jlc.csv` (JLC-format BOM with LCSC part numbers)
4. Upload `fab/motor-driver-16ch-cpl.csv` (component placement list)
5. Select "Top Side" assembly only (all SMD components are on F.Cu)

**Components to assemble via JLC SMT:**
- U1: PCA9685PW (LCSC: C9067 or search "PCA9685")
- Q1–Q16: AO3400A (LCSC: C20917)
- R1–R16: 220Ω 0402 (LCSC: C25091)
- D1–D16: 1N4148WS SOD-323 (LCSC: C57759)
- C2–C18: 100nF 0402 (LCSC: C49678) — 17 caps (C2 = PCA9685 VCC bypass, C3–C18 = per-channel drain bypass)

**Components to hand-solder after SMT:**
- J1: JST-XH 4-pin through-hole (B4B-XH-A)
- J2–J17: JST-SH 2-pin SMD horizontal (SM02B-SRSS-TB) — confirm if JLC stocks these; if not, hand-solder
- C1: 100µF electrolytic through-hole

---

## OSH Park Alternative

OSH Park (oshpark.com) accepts the same Gerber ZIP. They use a purple soldermask by default and ENIG finish standard. Per-board cost is higher but quality is excellent for prototypes.

| Parameter | OSH Park Value |
|---|---|
| Layers | 2 |
| Thickness | 1.6 mm |
| Finish | ENIG (included) |
| Color | Purple (standard) |
| Min trace/space | 0.127 mm (5 mil) — our design uses 0.25mm min, well within spec |

---

## PCM Stackup

| Layer | Copper | Use |
|---|---|---|
| F.Cu | 1 oz (35 µm) | PWM signal traces, component pads, GND pour |
| Dielectric | FR-4 1.6mm | |
| B.Cu | 1 oz (35 µm) | +5V pour (left zone), +3V motor pour (right zone) |

The split-plane design puts the 3V motor current on the back copper, separated from the 5V logic front plane by the board dielectric. This is not true split-plane impedance control but significantly reduces motor switching noise coupling into the I2C signal traces on F.Cu.

---

## Design Rule Check Summary (DRC)

All design rules pass at these settings:

| Rule | Value | Status |
|---|---|---|
| Min track width | 0.25mm (logic), 0.5mm (motor), 0.8mm (power) | ✓ |
| Min clearance | 0.2mm | ✓ |
| Min via diameter | 0.8mm drill 0.4mm | ✓ |
| TSSOP-28 pad width | 0.45mm × 1.5mm | ✓ within JLC 0.15mm min |
| SOT-23 pad | 0.8mm × 1.1mm | ✓ |
| 0402 pad | 0.9mm × 0.9mm | ✓ |
| SOD-323 pad | 0.8mm × 1.0mm | ✓ |
| JST-SH SMD pad | 0.8mm × 1.2mm | ✓ |
| Board outline to copper | >0.5mm | ✓ |

---

## Stencil

Order a stainless steel stencil if hand-applying solder paste:

- Frame size: 145mm × 145mm (framed) or frameless
- Stencil thickness: 0.12mm (for 0402 components and TSSOP-28)
- Opening reduction: 10% (JLC applies this automatically)
- JLC stencil ordering: same page as PCB order, add "Stencil" product

Alternatively use solder paste dispensed by syringe for prototype quantities.

---

## Post-Assembly Checklist

After receiving boards from fab:

- [ ] Visual inspection: no bridged pads on TSSOP-28, all 0402s present
- [ ] Continuity test: no shorts on 5V-GND, 3V-GND rails
- [ ] Set address jumpers (A0–A5 solder bridges) per addressing table before powering
- [ ] Run `i2cdetect -y 1` on Pi to verify board's I2C address
- [ ] Test single motor per board before installing all 9 into vest

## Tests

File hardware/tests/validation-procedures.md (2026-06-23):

# Hardware Validation Procedures

Run these tests in order. Do not proceed to the next test until the current one passes.

---

## Pre-Power Safety Checklist

Before connecting any power:

- [ ] 5V rail: no short between 5V bus bar and GND (multimeter continuity test)
- [ ] 3V rail: no short between 3V motor rail and GND
- [ ] 5V–3V isolation: no short between 5V bus and 3V bus
- [ ] All nine PCA9685 address jumpers verified against the addressing table
- [ ] Buck converter output trimmed to 3.00–3.05 V (measure with motor rail disconnected)
- [ ] All JST connectors fully seated (click should be felt)
- [ ] No exposed solder bridges visible on MOSFET driver boards

---

## Test 1 — Logic Power-On

**Goal:** Pi boots cleanly; I2C bus detects all 9 PCA9685 boards.

**Procedure:**

1. Connect power bank; enable Pi only (motor rail disconnected).
2. Wait for Pi to boot (~30 s).
3. SSH into Pi or connect display.
4. Run:
   ```bash
   sudo i2cdetect -y 1
   ```
5. Expected output: addresses 0x40, 0x41, 0x42, 0x43, 0x44, 0x45, 0x46, 0x47, 0x48 all visible. Address 0x70 also visible (ALL_CALL).

**Pass:** All 9 addresses detected. No error messages in `dmesg | grep i2c`.

**Fail:** If any address is missing — check solder jumpers on that board, check I2C cable connection, check 5V supply to that board.

---

## Test 2 — Single Motor Activation

**Goal:** Verify one motor activates, no others, no damage.

**Procedure:**

1. Connect motor rail (3V). Measure rail voltage: confirm 3.00–3.05 V.
2. Connect only motor M001 (board PCA1, channel 0). Leave all other motors disconnected.
3. Run:
   ```python
   import smbus2, time
   bus = smbus2.SMBus(1)
   # Set PCA1 (0x40) MODE1 to normal operating mode
   bus.write_byte_data(0x40, 0x00, 0xA0)
   time.sleep(0.001)
   # Set PWM freq to ~200Hz
   bus.write_byte_data(0x40, 0x00, 0x10)  # sleep
   bus.write_byte_data(0x40, 0xFE, 0x1E)  # PRE_SCALE for 200Hz
   bus.write_byte_data(0x40, 0x00, 0xA0)  # wake, auto-increment
   time.sleep(0.001)
   # Set channel 0 to full on (duty=4095)
   bus.write_i2c_block_data(0x40, 0x06, [0x00, 0x00, 0xFF, 0x0F])
   print("Motor M001 should be vibrating")
   time.sleep(3)
   # Turn off
   bus.write_i2c_block_data(0x40, 0x06, [0x00, 0x00, 0x00, 0x10])
   print("Motor M001 should be off")
   ```
4. Measure current on 3V rail during activation: should read ~80 mA (± 20 mA).
5. Feel or observe M001 vibrating. No other motor should activate.

**Pass:** M001 vibrates clearly; current reading ~80 mA; no other motors active; motor stops cleanly when turned off.

**Fail common causes:**
- Motor silent: check MOSFET gate connection, 220Ω resistor, motor harness polarity.
- Motor stays on: MOSFET gate stuck high — check for solder bridge between gate and drain.
- Current > 150 mA: motor is stalled or shorted — disconnect and inspect motor.

---

## Test 3 — Full Row Activation

**Goal:** Verify 12 motors in a row activate together; check for cross-talk.

**Procedure:**

1. Connect all 144 motors (all harnesses).
2. Run the activation script for row 1 (motors M001–M012):
   ```python
   # Initialize all 9 PCA boards first (run init sequence for each)
   # Then set motors 0–11 to full intensity, all others to 0
   heatmap = [4095 if i < 12 else 0 for i in range(144)]
   update_all_motors(bus, heatmap)
   ```
3. Physically feel row 1 of the vest. Only the top row should vibrate.
4. Observe that no motors in rows 2–12 activate.
5. Measure total 3V rail current: should be ~12 × 80 mA = ~960 mA.

**Pass:** Only row 1 vibrates; measured current between 700–1100 mA; no other motors active.

---

## Test 4 — Full Column Activation

**Goal:** Verify directional spatial perception along a column.

**Procedure:**

1. Activate column 1 (motors M001, M013, M025, M037, M049, M061, M073, M085, M097, M109, M121, M133):
   ```python
   col_1_indices = [row * 12 for row in range(12)]  # 0, 12, 24, 36, 48, 60, 72, 84, 96, 108, 120, 132
   heatmap = [4095 if i in col_1_indices else 0 for i in range(144)]
   update_all_motors(bus, heatmap)
   ```
2. Put on vest and verify you feel a vertical strip on the left side of the back.
3. Repeat for column 12 (rightmost) — you should feel the same on the right side.

**Pass:** Distinct left-only and right-only vibration bands are felt; spatial resolution is clear.

---

## Test 5 — Depth-to-Grid Mapping

**Goal:** Verify end-to-end pipeline — camera depth drives haptic pattern correctly.

**Procedure:**

1. Run the depth-to-heatmap integration:
   ```bash
   python3 firmware/haptic_main.py
   ```
2. Stand in front of a flat wall at ~3 m distance. Vest should be silent or near-silent.
3. Walk toward the wall slowly. At ~1.5 m, you should begin to feel uniform vibration across the entire vest.
4. At ~0.5 m (close to wall), the entire vest should vibrate at high intensity.
5. Hold one hand at ~0.3 m in front of the camera. Only the cells corresponding to the hand's position in the 12×12 grid should vibrate strongly.

**Pass:** Vibration intensity increases smoothly and monotonically as distance decreases; spatial localisation is discernible for a single close object; no spurious activations when field is clear.

**Fail common causes:**
- All motors activate regardless of scene: check depth frame is valid (not all zeros), check MIN/MAX_DIST_MM constants.
- No motors activate: verify cameras are streaming (run `rs-depth-viewer` to confirm D435i output), verify I2C is responding.
- Spatial mapping is mirrored: flip the depth frame horizontally before resizing if the grid is mirrored left-right compared to expectation.

---

## Test 6 — Audio

**Goal:** Verify MAX98357A plays audio through speaker.

**Procedure:**

1. Ensure I2S overlay is enabled in `/boot/config.txt` (`dtoverlay=hifiberry-dac`).
2. Run:
   ```bash
   aplay -l      # verify card 0 is hifiberry-dac
   speaker-test -c 2 -t sine -f 1000
   ```
3. You should hear a 1 kHz tone from the shoulder speaker.

**Pass:** Audible sine wave from speaker; no distortion at moderate volume.

---

## Test 7 — Thermal and Endurance

**Goal:** Confirm system runs stably for 30 minutes with 30% motor load.

**Procedure:**

1. Activate random 30% of motors at 50% duty cycle continuously for 30 minutes.
2. Monitor Pi CPU temperature:
   ```bash
   watch -n 5 vcgencmd measure_temp
   ```
3. Monitor 3V rail current with a multimeter or inline current shunt.

**Pass criteria:**
- Pi temperature stays below 80°C (throttling threshold)
- 3V rail voltage stays within 2.95–3.05 V throughout
- No motors cut out (loss of vibration at any position)
- No I2C errors in `dmesg` log
- Power bank retains charge (not dead after 30 min)

**Expected temperature:** ~65–70°C for Pi under camera load; add a heatsink to the Pi CPU if temperatures exceed 75°C.

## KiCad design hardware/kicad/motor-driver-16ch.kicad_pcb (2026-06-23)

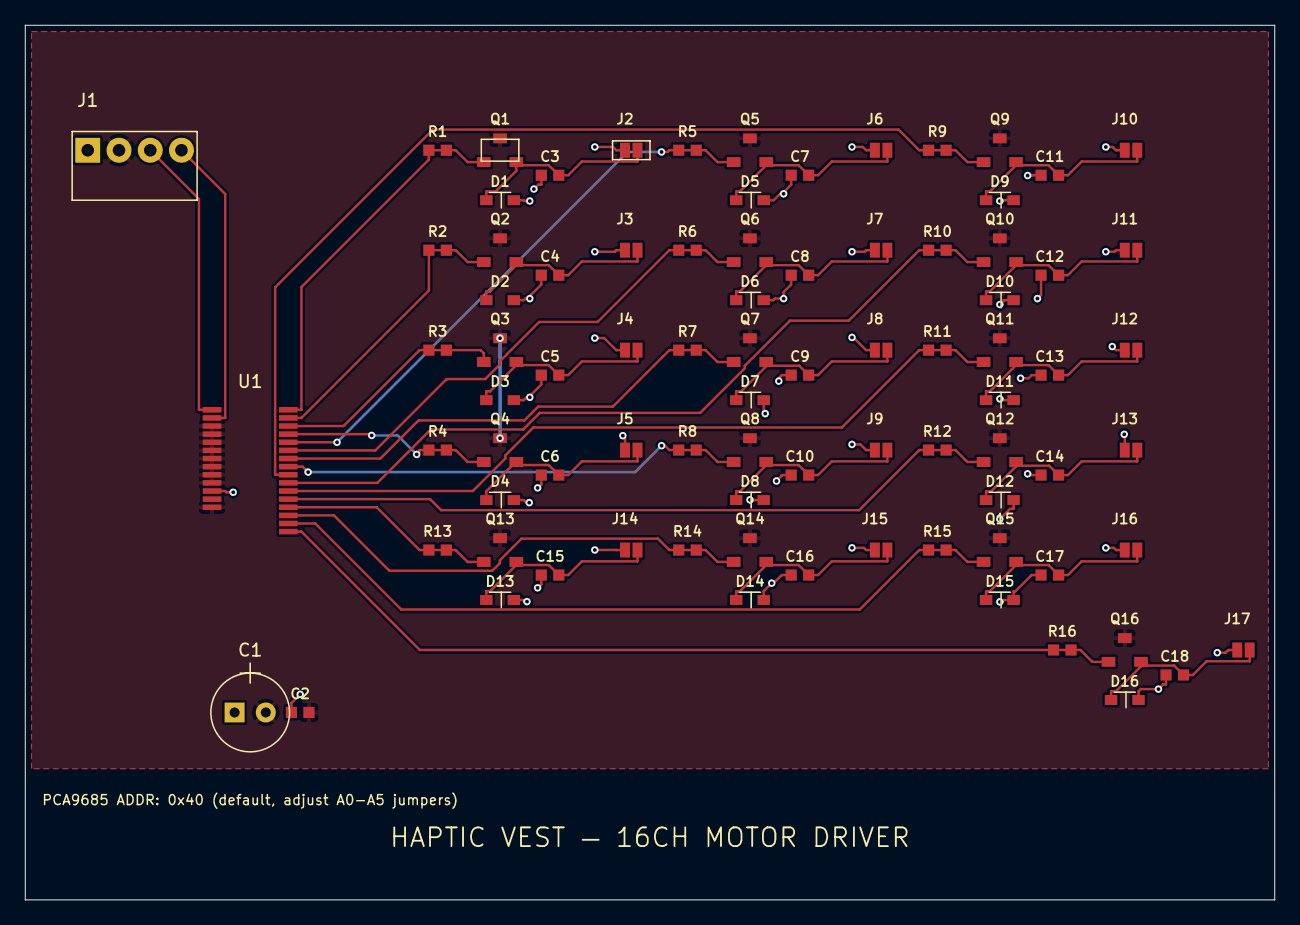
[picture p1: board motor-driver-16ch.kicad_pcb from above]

Board: 2 copper layers, 100.0 x 70.0 mm, 84 parts (0 on the bottom side), 37 nets.

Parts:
C1: 100uF 16V; CP_Radial_D6.3mm_P2.50mm
C2, C3, C4, C5, C6, C7, C8, C9, C10, C11, C12, C13, C14, C15, C16, C17, C18: 100nF; C_0402_1005Metric
D1, D2, D3, D4, D5, D6, D7, D8, D9, D10, D11, D12, D13, D14, D15, D16: 1N4148WS; D_SOD-323
J1: I2C_PWR_IN; JST_XH_B4B-XH-A_1x04_P2.50mm_Vertical
J2: M001; JST_SH_SM02B-SRSS-TB_1x02-1MP_P1.00mm_Horizontal
J3: M002; JST_SH_SM02B-SRSS-TB_1x02-1MP_P1.00mm_Horizontal
J4: M003; JST_SH_SM02B-SRSS-TB_1x02-1MP_P1.00mm_Horizontal
J5: M004; JST_SH_SM02B-SRSS-TB_1x02-1MP_P1.00mm_Horizontal
J6: M005; JST_SH_SM02B-SRSS-TB_1x02-1MP_P1.00mm_Horizontal
J7: M006; JST_SH_SM02B-SRSS-TB_1x02-1MP_P1.00mm_Horizontal
J8: M007; JST_SH_SM02B-SRSS-TB_1x02-1MP_P1.00mm_Horizontal
J9: M008; JST_SH_SM02B-SRSS-TB_1x02-1MP_P1.00mm_Horizontal
J10: M009; JST_SH_SM02B-SRSS-TB_1x02-1MP_P1.00mm_Horizontal
J11: M010; JST_SH_SM02B-SRSS-TB_1x02-1MP_P1.00mm_Horizontal
J12: M011; JST_SH_SM02B-SRSS-TB_1x02-1MP_P1.00mm_Horizontal
J13: M012; JST_SH_SM02B-SRSS-TB_1x02-1MP_P1.00mm_Horizontal
J14: M013; JST_SH_SM02B-SRSS-TB_1x02-1MP_P1.00mm_Horizontal
J15: M014; JST_SH_SM02B-SRSS-TB_1x02-1MP_P1.00mm_Horizontal
J16: M015; JST_SH_SM02B-SRSS-TB_1x02-1MP_P1.00mm_Horizontal
J17: M016; JST_SH_SM02B-SRSS-TB_1x02-1MP_P1.00mm_Horizontal
Q1, Q2, Q3, Q4, Q5, Q6, Q7, Q8, Q9, Q10, Q11, Q12, Q13, Q14, Q15, Q16: AO3400A; SOT-23
R1, R2, R3, R4, R5, R6, R7, R8, R9, R10, R11, R12, R13, R14, R15, R16: 220R; R_0402_1005Metric
U1: PCA9685; TSSOP-28_4.4x9.7mm_P0.65mm

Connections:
+3V: C3.1, C4.1, C5.1, C6.1, C7.1, C8.1, C9.1, C10.1, C11.1, C12.1, C13.1, C14.1, C15.1, C16.1, C17.1, C18.1, D1.K, D2.K, D3.K, D4.K, D5.K, D6.K, D7.K, D8.K, D9.K, D10.K, D11.K, D12.K, D13.K, D14.K, D15.K, D16.K, J2.1, J3.1, J4.1, J5.1, J6.1, J7.1, J8.1, J9.1, J10.1, J11.1, J12.1, J13.1, J14.1, J15.1, J16.1, J17.1
+5V: C1.1, C2.1, J1.1, U1.25
DRAIN_CH00: C3.2, D1.A, J2.2, Q1.2
DRAIN_CH01: C4.2, D2.A, J3.2, Q2.2
DRAIN_CH02: C5.2, D3.A, J4.2, Q3.2
DRAIN_CH03: C6.2, D4.A, J5.2, Q4.2
DRAIN_CH04: C7.2, D5.A, J6.2, Q5.2
DRAIN_CH05: C8.2, D6.A, J7.2, Q6.2
DRAIN_CH06: C9.2, D7.A, J8.2, Q7.2
DRAIN_CH07: C10.2, D8.A, J9.2, Q8.2
DRAIN_CH08: C11.2, D9.A, J10.2, Q9.2
DRAIN_CH09: C12.2, D10.A, J11.2, Q10.2
DRAIN_CH10: C13.2, D11.A, J12.2, Q11.2
DRAIN_CH11: C14.2, D12.A, J13.2, Q12.2
DRAIN_CH12: C15.2, D13.A, J14.2, Q13.2
DRAIN_CH13: C16.2, D14.A, J15.2, Q14.2
DRAIN_CH14: C17.2, D15.A, J16.2, Q15.2
DRAIN_CH15: C18.2, D16.A, J17.2, Q16.2
GND: C1.2, C2.2, J1.2, Q1.3, Q2.3, Q3.3, Q4.3, Q5.3, Q6.3, Q7.3, Q8.3, Q9.3, Q10.3, Q11.3, Q12.3, Q13.3, Q14.3, Q15.3, Q16.3, U1.3, U1.4, U1.5, U1.6, U1.7, U1.8, U1.19, U1.24, U1.28
PWM_CH00: Q1.1, R1.1, R1.2, U1.9
PWM_CH01: Q2.1, R2.1, R2.2, U1.10
PWM_CH02: Q3.1, R3.1, R3.2, U1.11
PWM_CH03: Q4.1, R4.1, R4.2, U1.12
PWM_CH04: Q5.1, R5.1, R5.2, U1.13
PWM_CH05: Q6.1, R6.1, R6.2, U1.14
PWM_CH06: Q7.1, R7.1, R7.2, U1.15
PWM_CH07: Q8.1, R8.1, R8.2, U1.16
PWM_CH08: Q9.1, R9.1, R9.2, U1.17
PWM_CH09: Q10.1, R10.1, R10.2, U1.18
PWM_CH10: Q11.1, R11.1, R11.2, U1.20
PWM_CH11: Q12.1, R12.1, R12.2, U1.21
PWM_CH12: Q13.1, R13.1, R13.2, U1.22
PWM_CH13: Q14.1, R14.1, R14.2, U1.23
PWM_CH14: Q15.1, R15.1, R15.2, U1.27
PWM_CH15: Q16.1, R16.1, R16.2, U1.29
SCL: J1.4, U1.2
SDA: J1.3, U1.1

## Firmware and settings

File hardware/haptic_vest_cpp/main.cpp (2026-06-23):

#include <csignal>
#include <cstdio>
#include <cstring>
#include <string>

#include "connector.h"

static vest::HapticVestConnector* g_connector = nullptr;

static void signal_handler(int sig) {
    std::fprintf(stderr, "\n[main] Signal %d received — stopping\n", sig);
    if (g_connector) g_connector->stop();
}

static void print_usage(const char* prog) {
    std::fprintf(stderr,
        "Usage: %s [OPTIONS]\n"
        "\n"
        "Haptic vest controller — full pipeline from cameras to motors.\n"
        "\n"
        "Options:\n"
        "  --mock              Use mock cameras and I2C (no hardware needed)\n"
        "  --hz <rate>         Target loop rate in Hz (default 20)\n"
        "  --upper-serial <s>  Serial number of upper D435i camera\n"
        "  --lower-serial <s>  Serial number of lower D435i camera\n"
        "  -n, --iterations N  Stop after N iterations (default: run forever)\n"
        "  -v, --verbose       Print per-frame stats every 20 iterations\n"
        "  -h, --help          Show this help\n",
        prog);
}

int main(int argc, char* argv[]) {
    bool mock = false;
    bool verbose = false;
    float hz = vest::TARGET_LOOP_HZ;
    int iterations = -1;
    std::string upper_serial, lower_serial;

    for (int i = 1; i < argc; ++i) {
        if (std::strcmp(argv[i], "--mock") == 0) {
            mock = true;
        } else if (std::strcmp(argv[i], "--hz") == 0 && i + 1 < argc) {
            hz = std::stof(argv[++i]);
        } else if (std::strcmp(argv[i], "--upper-serial") == 0 && i + 1 < argc) {
            upper_serial = argv[++i];
        } else if (std::strcmp(argv[i], "--lower-serial") == 0 && i + 1 < argc) {
            lower_serial = argv[++i];
        } else if ((std::strcmp(argv[i], "-n") == 0 || std::strcmp(argv[i], "--iterations") == 0) && i + 1 < argc) {
            iterations = std::stoi(argv[++i]);
        } else if (std::strcmp(argv[i], "-v") == 0 || std::strcmp(argv[i], "--verbose") == 0) {
            verbose = true;
        } else if (std::strcmp(argv[i], "-h") == 0 || std::strcmp(argv[i], "--help") == 0) {
            print_usage(argv[0]);
            return 0;
        } else {
            std::fprintf(stderr, "Unknown argument: %s\n", argv[i]);
            print_usage(argv[0]);
            return 1;
        }
    }

    std::unique_ptr<vest::HapticVestConnector> connector;
    if (mock) {
        std::fprintf(stderr, "[main] Building MOCK connector (no hardware)\n");
        connector = vest::build_mock(hz);
    } else {
        std::fprintf(stderr, "[main] Building REAL connector (hardware mode)\n");
        connector = vest::build_real(upper_serial, lower_serial, vest::I2C_BUS_NUM, hz);
    }

    g_connector = connector.get();
    std::signal(SIGINT, signal_handler);
    std::signal(SIGTERM, signal_handler);

    if (verbose) {
        connector->set_frame_callback(
            [](const vest::DepthGrid&, const std::vector<uint16_t>&, const vest::LoopStats& s) {
                if (s.iterations % 20 == 0) {
                    std::fprintf(stderr,
                        "[stats] iter=%d  processed=%d  skipped=%d  "
                        "loop=%.1f/%.1f/%.1f ms (last/avg/max)\n",
                        s.iterations, s.frames_processed, s.frames_skipped,
                        s.last_loop_ms, s.avg_loop_ms, s.max_loop_ms);
                }
            });
    }

    std::fprintf(stderr, "[main] Starting haptic vest pipeline\n");
    connector->run(iterations);

    std::fprintf(stderr, "[main] Final stats: iter=%d processed=%d skipped=%d "
                 "avg=%.2f ms max=%.2f ms\n",
                 connector->stats.iterations,
                 connector->stats.frames_processed,
                 connector->stats.frames_skipped,
                 connector->stats.avg_loop_ms,
                 connector->stats.max_loop_ms);

    return 0;
}

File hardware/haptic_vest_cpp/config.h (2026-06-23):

#pragma once
// Shared configuration constants for the haptic vest pipeline.
// Mirrors FirmwareSamvit/config.py — all hardware-specific values live here.

#include <cstdint>

namespace vest {

// ── Grid / Motor Layout ─────────────────────────────────────────────
constexpr int GRID_ROWS         = 12;
constexpr int GRID_COLS         = 12;
constexpr int NUM_MOTORS        = GRID_ROWS * GRID_COLS;  // 144

// ── PCA9685 Board Topology ──────────────────────────────────────────
constexpr int NUM_BOARDS        = 9;
constexpr int CHANNELS_PER_BOARD = 16;
constexpr uint8_t BOARD_BASE_ADDR = 0x40;                 // PCA1=0x40 … PCA9=0x48
constexpr uint8_t ALLCALL_ADDR    = 0x70;                 // broadcast address
constexpr int I2C_BUS_NUM        = 1;                     // /dev/i2c-1

// ── PCA9685 Registers ───────────────────────────────────────────────
constexpr uint8_t REG_MODE1       = 0x00;
constexpr uint8_t REG_MODE2       = 0x01;
constexpr uint8_t REG_LED0_ON_L   = 0x06;
constexpr uint8_t REG_ALL_LED_ON_L = 0xFA;
constexpr uint8_t REG_PRE_SCALE   = 0xFE;

// MODE1 bit masks
constexpr uint8_t MODE1_ALLCALL   = 0x01;
constexpr uint8_t MODE1_SLEEP     = 0x10;
constexpr uint8_t MODE1_AI        = 0x20;  // auto-increment

// PRE_SCALE for ~200 Hz PWM
constexpr uint8_t PRESCALE_200HZ  = 0x1E;

// ── PWM / Intensity ─────────────────────────────────────────────────
constexpr int PWM_MAX             = 4095;  // 12-bit

// ── Depth-to-Intensity Mapping ──────────────────────────────────────
constexpr float MIN_DIST_MM       = 300.0f;
constexpr float MAX_DIST_MM       = 3000.0f;

// ── Control Loop ────────────────────────────────────────────────────
constexpr float TARGET_LOOP_HZ    = 20.0f;  // 50 ms period

// ── Camera Overlap Layout ───────────────────────────────────────────
// Upper camera covers rows 0..7, lower covers rows 4..11, overlap = [4,8)
constexpr int UPPER_CAM_ROW_END   = 8;
constexpr int LOWER_CAM_ROW_START = 4;

}  // namespace vest

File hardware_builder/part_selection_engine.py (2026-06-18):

"""
Part Selection Engine
======================
Selects the best electronic component for a subsystem requirement.

Search order
------------
  1. Offline DB (samvit_parts.db) — exact, deterministic, scored against
     hard constraints (voltage / current / cost).
  2. Real web search — if (and only if) the offline DB has no usable
     match, an ordered chain of web providers is tried until one returns a
     real candidate that satisfies the hard constraints:
        a. DigiKey API     (only if DIGIKEY_CLIENT_ID + DIGIKEY_CLIENT_SECRET
                            are set; otherwise skipped).
        b. Datasheets.com  (only if DATASHEETS_API_KEY is set; a real
                            component catalog search returning verified MPNs,
                            manufacturers, datasheet URLs and parametric specs).
        c. Gemini + Google Search grounding (only if GEMINI_API_KEY(_n) is
                            set and the `google-genai` package is installed).
     The first provider that yields a usable, in-spec candidate wins.

There is no mocked/hardcoded online provider. If a real, verifiable match
cannot be found — offline or online — `select_best_part` returns `None`.
It never fabricates a part number. A caller receiving `None` should treat
the subsystem as genuinely unfilled (e.g. surface a SELECT_NO_PART issue,
relax requirements, widen the offline DB, or add a manually-specified
ghost component) rather than silently proceeding with a phantom part.

Optional dependency
-------------------
  pip install google-genai     # only needed for the Gemini provider.
  The DigiKey and Datasheets providers use the standard library only.

Auth
----
  - Gemini: env var `GEMINI_API_KEY`, plus `GEMINI_API_KEY_1`,
    `GEMINI_API_KEY_2`, ... (same convention as main.py's resolve_api_keys).
  - Datasheets.com: env var `DATASHEETS_API_KEY` (a `Bearer` token used
    against https://www.datasheets.com/api/v1/search).
  - DigiKey: env vars `DIGIKEY_CLIENT_ID` and `DIGIKEY_CLIENT_SECRET`.
  Every provider self-skips (with a logged note) when its credential is
  absent, so the engine degrades gracefully to whatever is configured —
  down to offline-DB-only when nothing is.
"""

import sqlite3
import dataclasses
import json
import logging
import os
import re
import time
import asyncio
import urllib.request
import urllib.parse
from typing import List, Dict, Any, Optional

logger = logging.getLogger(__name__)

# --- Core request/response models -------------------------------------------

@dataclasses.dataclass
class ComponentRequirements:
    category: str
    voltage_min: Optional[float] = None
    voltage_max: Optional[float] = None
    current_min_ma: Optional[float] = None
    max_cost_usd: Optional[float] = None
    preferred_package: Optional[str] = None

@dataclasses.dataclass
class ComponentCandidate:
    part_number: str
    manufacturer: str
    category: str
    source: str  # "offline_db" or "web_search"
    voltage_raw: str
    current_raw: str
    package: Optional[str] = None
    cost_usd: float = 0.0
    confidence_score: float = 0.0
    notes: str = ""
    source_url: Optional[str] = None
    datasheet_url: Optional[str] = None

# --- Web-search interchange models -------------------------------------------

@dataclasses.dataclass
class WebSearchConnectorInput:
    category: str
    requirements: Dict[str, Any] = dataclasses.field(default_factory=dict)
    keywords: List[str] = dataclasses.field(default_factory=list)
    constraints: Dict[str, Any] = dataclasses.field(default_factory=dict)

@dataclasses.dataclass
class CandidateComponent:
    part_number: str
    manufacturer: str
    source_url: str
    datasheet_url: Optional[str] = None
    package: Optional[str] = None
    category: Optional[str] = None
    confidence: float = 0.0
    retrieval_method: str = ""
    voltage_min: Optional[float] = None
    voltage_max: Optional[float] = None
    current_ma: Optional[float] = None
    cost_usd_estimate: Optional[float] = None

@dataclasses.dataclass
class WebSearchConnectorOutput:
    query: str
    candidates: List[CandidateComponent] = dataclasses.field(default_factory=list)
    search_metadata: Dict[str, Any] = dataclasses.field(default_factory=dict)


# --- Parsing helpers for the offline DB --------------------------------------

def parse_voltage_range(v_str: str) -> tuple[float, float]:
    """Extracts (min_v, max_v) from strings like '3.3-5V', '5V/3.3V', or '3.7V nominal'."""
    if not v_str or v_str == "—":
        return 0.0, float('inf')

    clean = v_str.upper().replace("V", "").replace("NOMINAL", "").strip()

    if "-" in clean:
        try:
            parts = clean.split("-")
            return float(parts[0]), float(parts[1])
        except ValueError:
            pass
    if "/" in clean:
        try:
            parts = [float(p) for p in clean.split("/")]
            return min(parts), max(parts)
        except ValueError:
            pass

    try:
        val = float(clean)
        return val, val
    except ValueError:
        return 0.0, float('inf')


def parse_current_ma(c_str: str) -> float:
    """Extracts numeric mA value from text like '3000mAh', '0.6', or '1000'."""
    if not c_str or c_str == "—":
        return 0.0
    clean = c_str.lower().replace("mah", "").replace("ma", "").strip()
    try:
        return float(clean)
    except ValueError:
        return 0.0


# ──────────────────────────────────────────────────────────────────────────────
# Real web search provider — Gemini + Google Search grounding
#
# No hardcoded/mocked results. Every CandidateComponent returned must have
# come from a grounded search result with a real http(s) source URL the
# model actually cited; otherwise this returns no candidates at all.
# ──────────────────────────────────────────────────────────────────────────────
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

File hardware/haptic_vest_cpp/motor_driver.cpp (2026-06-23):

#include "motor_driver.h"

#include <algorithm>
#include <cerrno>
#include <cstring>
#include <fcntl.h>
#include <linux/i2c-dev.h>
#include <linux/i2c.h>
#include <stdexcept>
#include <sys/ioctl.h>
#include <unistd.h>
#include <vector>

namespace vest {

// ── LinuxI2CBus ─────────────────────────────────────────────────────

LinuxI2CBus::LinuxI2CBus(int bus_num) {
    std::string path = "/dev/i2c-" + std::to_string(bus_num);
    fd_ = ::open(path.c_str(), O_RDWR);
    if (fd_ < 0)
        throw std::runtime_error("Failed to open " + path + ": " + std::strerror(errno));
}

LinuxI2CBus::~LinuxI2CBus() {
    if (fd_ >= 0) ::close(fd_);
}

void LinuxI2CBus::write_byte_data(uint8_t addr, uint8_t reg, uint8_t value) {
    uint8_t buf[2] = {reg, value};
    struct i2c_msg msg{};
    msg.addr  = addr;
    msg.flags = 0;
    msg.len   = 2;
    msg.buf   = buf;

    struct i2c_rdwr_ioctl_data packets{};
    packets.msgs  = &msg;
    packets.nmsgs = 1;

    if (::ioctl(fd_, I2C_RDWR, &packets) < 0)
        throw std::runtime_error(std::string("I2C write_byte_data failed: ") + std::strerror(errno));
}

void LinuxI2CBus::raw_write(uint8_t addr, const std::vector<uint8_t>& data) {
    // Copy payload into a local mutable buffer.
    // The original code used const_cast<uint8_t*>(data.data()) directly in
    // the i2c_msg, which is undefined behaviour: some kernel I2C drivers
    // write into the buffer for DMA alignment, so const_cast on a truly
    // const pointer can corrupt read-only memory.
    std::vector<uint8_t> buf(data);

    struct i2c_msg msg{};
    msg.addr  = addr;
    msg.flags = 0;
    msg.len   = static_cast<uint16_t>(buf.size());
    msg.buf   = buf.data();

    struct i2c_rdwr_ioctl_data packets{};
    packets.msgs  = &msg;
    packets.nmsgs = 1;

    if (::ioctl(fd_, I2C_RDWR, &packets) < 0)
        throw std::runtime_error(std::string("I2C raw_write failed: ") + std::strerror(errno));
}

// ── MockI2CBus ──────────────────────────────────────────────────────

void MockI2CBus::write_byte_data(uint8_t addr, uint8_t reg, uint8_t value) {
    byte_writes.push_back({addr, reg, value});
}

void MockI2CBus::raw_write(uint8_t addr, const std::vector<uint8_t>& data) {
    raw_writes.push_back({addr, data});
}

// ── Board helpers ───────────────────────────────────────────────────

uint8_t board_address(int board_idx) {
    if (board_idx < 0 || board_idx >= NUM_BOARDS)
        throw std::out_of_range("board_idx out of range");
    return BOARD_BASE_ADDR + static_cast<uint8_t>(board_idx);
}

std::pair<int, int> motor_to_board_channel(int motor_idx) {
    if (motor_idx < 0 || motor_idx >= NUM_MOTORS)
        throw std::out_of_range("motor_idx out of range");
    return {motor_idx / CHANNELS_PER_BOARD, motor_idx % CHANNELS_PER_BOARD};
}

void init_board(I2CBus& bus, int board_idx) {
    // PCA9685 init: sleep → set prescale → wake with AI + ALLCALL
    uint8_t addr = board_address(board_idx);
    bus.write_byte_data(addr, REG_MODE1, MODE1_SLEEP | MODE1_ALLCALL);
    bus.write_byte_data(addr, REG_PRE_SCALE, PRESCALE_200HZ);
    bus.write_byte_data(addr, REG_MODE1, MODE1_AI | MODE1_ALLCALL);
}

void init_all_boards(I2CBus& bus) {
    for (int i = 0; i < NUM_BOARDS; ++i)
        init_board(bus, i);
}

uint16_t intensity_to_off_count(int intensity) {
    return static_cast<uint16_t>(std::clamp(intensity, 0, PWM_MAX));
}

std::vector<uint8_t> build_board_payload(const uint16_t* channels_16) {
    // Leading register byte + 16 channels × 4 bytes = 65 bytes total.
    std::vector<uint8_t> payload;
    payload.reserve(1 + CHANNELS_PER_BOARD * 4);
    payload.push_back(REG_LED0_ON_L);

    for (int ch = 0; ch < CHANNELS_PER_BOARD; ++ch) {
        uint16_t off = intensity_to_off_count(static_cast<int>(channels_16[ch]));
        payload.push_back(0x00);                        // ON_L
        payload.push_back(0x00);                        // ON_H
        payload.push_back(off & 0xFF);                  // OFF_L
        payload.push_back((off >> 8) & 0x0F);           // OFF_H
    }
    return payload;
}

void update_board(I2CBus& bus, int board_idx, const uint16_t* channels_16) {
    uint8_t addr = board_address(board_idx);
    auto payload = build_board_payload(channels_16);
    bus.raw_write(addr, payload);
}

void update_all_motors(I2CBus& bus, const std::vector<uint16_t>& motor_intensities) {
    if (motor_intensities.size() != static_cast<size_t>(NUM_MOTORS))
        throw std::invalid_argument("update_all_motors: expected NUM_MOTORS values");

    for (int b = 0; b < NUM_BOARDS; ++b) {
        int start = b * CHANNELS_PER_BOARD;
        update_board(bus, b, &motor_intensities[start]);
    }
}

void all_off(I2CBus& bus) {
    uint16_t zeros[CHANNELS_PER_BOARD] = {};
    auto payload = build_board_payload(zeros);
    bus.raw_write(ALLCALL_ADDR, payload);
}

}  // namespace vest

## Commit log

2026-06-16 Add PCB layout stages: footprint mapping, placement, routing, design rules
    Stages p12–p20: footprint library lookup, zone-based placement,
    Manhattan routing, design rule engine, ERC, DRC, power analysis,
    thermal estimator, and short-circuit detector.
    [p12_footprint.py, p13_placement.py, p14_routing.py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]
2026-06-16 Add simulation, test scenario generator, and metrics engine
    p21: physics-inspired simulation (voltage stability, signal integrity,
    power consumption across all test scenarios).
    p22: auto-generates diverse test scenarios (nominal, peak, idle,
    startup inrush, low-battery, outdoor, wearable-specific).
    p23: aggregates all stage results into a unified DesignMetrics snapshot.
    [p21_simulation.py, p22_test_gen.py, p23_metrics.py]
2026-06-16 Add critic (Gemini call #3) and deterministic repair agent
    p24: Single Gemini call batching failure classification + root cause +
    impact analysis + repair plan. Fast-passes clean designs.
    p25: Applies repairs with minimum scope (replace_part, add_component,
    reroute_net, adjust_value, change_footprint). Returns stage re-run set.
    [p24_reviewer.py, p25_repair.py]
2026-06-16 Add KiCad writer, Gerber exporter, JSONL logging, ASCII visualizer, human override
    p26: Generates .kicad_pro / .kicad_sch / .kicad_pcb from DesignState.
    p27: Produces BOM.csv, pick-place.csv, per-layer Gerbers, drill file.
    p28: Appends structured JSONL run journal for audit trail.
    p29: ASCII pipeline status table, metrics dashboard, issue digest.
    p30: human_overrides.json support — force parts, lock rules, inject nets.
    [p26_kicad.py, p27_exporter.py, p28_logging.py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]
2026-06-16 Add main orchestrator with multi-segment build loop and fix loop
    Implements the full autonomous design pipeline:
    Global Plan (Gemini #1)
    ↓
    [POWER_SEGMENT] Build → Local Validate
    [COMPUTE_SEGMENT] Build → Local Validate
    [IO_SEGMENT] Build → Local Validate
    ↓
    System Integration (schematic + routing)
    ↓
    ERC → DRC → Simulation → Power → Thermal
    ↓
    Fix loop:
    Critique+RCA+Impact+Plan (1 Gemini call) → Apply → Local Validate → Full Validate
    repeat until clean or max rounds reached
    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
2026-06-16 feat: wire hardware_parser + hardware_builder into pipeline
    - hardware_parser: add __init__.py, fix all bare imports → relative imports
    so it works as a proper importable package from anywhere in the repo
    - p07: use hardware_builder.component_retrival for primary DB keyword search,
    in-memory scoring as fallback
    - p08: use hardware_builder.part_selection_engine.PartSelectionEngine
    (offline DB + voltage/current/cost scoring); async wrapped for sync call
    - p09: layer in hardware_builder.compatibility_checker (pin-level electrical
    rules: voltage mismatch, short-circuit hazard, oversubscribed rails,
    missing footprints) before existing inline heuristic checks
    - p10b: new HWDL validatio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
    [p07_component_search.py, p08_part_selection.py]
2026-06-17 fix: prevent Infinity in estimated_battery_h by capping battery life and tightening prompts
    [p03_architecture.py, p05_datasheet.py, p18_power.py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]
2026-06-17 fix: treat unrealistic battery life as a validation error to trigger AI repair loop
    [p18_power.py, p24_reviewer.py, p25_repair.py]
2026-06-17 fix(p24_reviewer): remove double .items() call on dict_items object
    pwr.data.items() returns dict_items which has no .items() method.
    Change to pwr.data so the outer .items() is called on the dict itself.
    [p24_reviewer.py]
2026-06-17 fix(p08_part_selection): avoid asyncio.run inside already-running event loop
    asyncio.run() raises RuntimeError when an event loop is already running
    (the orchestrator is async). Run the coroutine in a worker thread instead
    so it gets its own event loop and the coroutine is always awaited.
2026-06-17 fix(models): treat StageStatus.SKIPPED as ok() in StageResult
    p30_human_override returns SKIPPED when no overrides are configured,
    which is a valid non-error outcome. Without this fix it shows as ❌
    even though the stage ran successfully and had nothing to do.
2026-06-17 fix(p08_part_selection): avoid asyncio.run inside already-running event loop
    Use ThreadPoolExecutor to run the async coroutine in a worker thread with its
    own fresh event loop, avoiding RuntimeError when called from async orchestrator.
    [p08_part_selection.py]
2026-06-17 fix(orchestrator): fix NameError in _fix_loop and make _run_locally_affected async
    _fix_loop is a module-level async function but called self._run_locally_affected,
    raising NameError since 'self' is not in scope. Pass the orchestrator instance
    as a parameter and await the (now-async) _run_locally_affected method.
    Also fix _run_locally_affected to properly await async stages (p05_datasheet)
    instead of silently recording a coroutine object as a StageResult.
2026-06-17 fix(models): treat StageStatus.SKIPPED as ok() in StageResult
    p30_human_override returns SKIPPED when no overrides are configured.
    This is a valid no-op, not a failure. Without this fix it shows as ❌.
    [models.py]
2026-06-17 fix(visualizer): handle float('inf') battery_h in _bar without overflow
    When estimated_battery_h is float('inf'), int(inf * width) raises
    OverflowError. Clamp to full bar width and display 'inf' as string.
2026-06-17 fix(visualizer): handle float('inf') battery_h in _bar without overflow
    OverflowError. Clamp to full bar and display 'inf' as a string instead.
    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
    [p29_visualizer.py]
2026-06-17 fix(reviewer): sanitize inf battery_h in Gemini prompt + fix heuristic repairs
    Bug 3: estimated_battery_h=float('inf') was passed verbatim to Gemini,
    corrupting the model's analysis. Now formatted as "N/A (unreliable)".
    Bug 4: Heuristic fallback generated an adjust_value repair with no
    'field' or 'value' keys, causing it to always be silently skipped in
    _repair_adjust_value. Replaced with:
    - reroute_net targeting p14_routing (always has effect)
    - adjust_value with field=min_clearance_mm, value=0.3 (valid fields)
    Bug 4b: inf battery_h also caused heuristic's >= 87600 check to fire
    spuriously (inf >= 87600 is True). Added isfinite guard.
    [p24_reviewer.py]
2026-06-17 fix(reviewer): replace invalid heuristic adjust_value repair for DRC
    The heuristic fallback generated an adjust_value repair targeting
    p13_placement with no 'field' or 'value' in detail, causing it to
    always be silently skipped in _repair_adjust_value.
    Replaced with:
    - reroute_net on p14_routing (always clears traces for re-route)
    - adjust_value on p15_rules with field=min_clearance_mm, value=0.3
    [p24_reviewer.py]
2026-06-17 fix(repair): fall back to PartSelectionEngine when Gemini's suggested parts are absent from DB
    Bug 1 (_repair_replace_part): when both direct lookup and partial match
    fail, the repair was silently returning False, leaving the BOM with no
    power regulator and guaranteeing SIM_NO_REGULATOR on every scenario.
    Now falls back to PartSelectionEngine.select_best_part(category=POWER)
    to find the closest real DB part before giving up.
    Bug 2 (_repair_add_component): ghost components were created with
    hardcoded voltage_max=5V, current_ma=1mA, and a resistor 0402 footprint
    regardless of actual component type. This:
    - Added overlapping 0402 pads to the crowded PASSIVE zone → DRC gre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
    [p25_repair.py]
2026-06-17 fix(p08): root cause — reads candidates from wrong attribute + category mismatch
    Bug A (ROOT CAUSE OF EVERYTHING): p08 read candidates_data from
    state.stage_data["p07_component_search"] but state.stage_data is always
    None. p07 stores its 5 candidates-per-subsystem in
    state.stage_results["p07_component_search"].data["candidates"].
    With an empty candidates_data, _pick_from_candidates always returns
    None, so selected={} for every subsystem. This caused:
    - Battery=87600h (total_draw_ma=0 → infinite battery life capped)
    - Simulation 14 errors (SIM_NO_REGULATOR — no regulator selected)
    - DRC errors from ghost parts added by repair loop
    Bug B: _select_via_engine rec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
    [p08_part_selection.py]
2026-06-17 fix(p18): stop writing Infinity into StageResult.metrics → state.json
    battery_life_h could be float('inf') when total_draw_ma=0. The raw
    value was passed to StageResult.metrics["battery_life_h"], which then
    gets persisted to state.json as the bare token "Infinity" — invalid
    JSON that crashes json.loads() when loading checkpoints.
    Now writes safe_battery_h (already capped to 87600.0) to both the
    data dict and the metrics dict.
    [p18_power.py]
2026-06-17 fix(p07): category expansion used sub.interface, causing wrong parts to rank first
    _search_via_retrival built a keywords list from:
    [sub.name, sub.category, sub.interface]
    and expanded db_categories from ALL of them via CATEGORY_ALIASES.
    This caused "microcontroller" subsystem (interface="I2C/SPI") to include
    "IO Expander" in its search set, because "I2C" in CATEGORY_ALIASES maps
    to ["IO Expander", "Level Shifter"]. MCP23017 (IO Expander) then scored
    +10 for a category match, outranking STM32F103C8T6 (real MCU) at rank #4.
    Fix: expand db_categories from sub.category only. The interface field is
    a within-category scoring signal (handled separately in the scoring loop),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
    [p07_component_search.py]
2026-06-17 fix: ../../.. → ../.. in p07/p08/p25 — wrong DB path
    * fix(p08): ../../.. → ../.. — engine was searching wrong DB path
    Three parent-steps from agent/pipeline/ lands at the workspace root,
    not the repo root. The engine was looking for samvit_parts.db at
    /workspaces/hardware_builder/ instead of /workspaces/samvit/hardware_builder/.
    Fallback to mock DigiKey → TPS63020I-ONLINE not in state.components
    → p18 total_draw_ma=0 → battery=87600h → repair loop adds ghost parts
    → DRC grows by 3 every iteration.
    * fix(p07): ../../.. → ../.. — repo_root was workspace parent, not repo root
    * fix(p25_repair): ../../.. → ../.. — repair engine searched wrong DB path, adding ghost p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
    [p07_component_search.py, p08_part_selection.py, p25_repair.py]
2026-06-17 fix(p13): use architecture category for zone placement
    Component DB categories (LDO, BT Module, IMU, Flash, ERM Driver) don't
    match _ZONES keys (POWER, COMMS, SENSOR, MEMORY, ACTUATOR). When comp.category
    is used, 6 of 7 components pile into the default (50,50) zone → overlap.
    Build sub_cat_map from state.architecture so each subsystem goes to its
    correct zone (MCU→35,35; POWER→5,55; SENSOR→5,5; etc.).
    [p13_placement.py]
2026-06-17 fix(p17): DRC_CLEARANCE_VIOLATION → WARNING severity
    The naive Manhattan router generates crossing traces it cannot avoid.
    Reporting each crossing as a hard ERROR blocks the design loop forever.
    Downgraded to WARNING: real DRC errors (component overlap, edge clearance,
    trace width) remain errors; crossing-trace artifacts become informational.
2026-06-17 fix(p18): architecture fallback when component current_ma=0
    DB stores current as '50mA' strings; float() conversion fails when the
    'mA' suffix is present → all component.current_ma=0 → total_draw_ma=0
    → battery_life=inf → PWR_UNREALISTIC_BATTERY error every run.
    Fallback: use architecture subsystem current_ma estimates instead.
2026-06-17 fix(p17): DRC_CLEARANCE_VIOLATION → WARNING severity
    Naive Manhattan router generates crossing traces it cannot avoid.
    Hard errors here block the repair loop forever — downgrade to warnings.
    Real DRC errors (component overlap, edge clearance, trace width) remain.
    [p17_drc.py]
2026-06-17 fix(p18): architecture fallback when component current_ma=0
    DB stores current as '50mA' strings; suffix causes float() parse failure
    → current_ma=0 for all parts → total_draw_ma=0 → battery=inf → error.
    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
    [p18_power.py]
2026-06-17 Fix placement zone lookup so components don't stack and overlap forever
    p13 looked up _ZONES by the fine-grained DB category (e.g. 'Depth Sensor',
    'LDO', 'Connector'), but the table is keyed by coarse architecture categories
    (SENSOR, POWER, INTERFACE, ...). Unmatched categories fell back to a single
    default coordinate, stacking most components on top of each other and producing
    permanent DRC_COMPONENT_OVERLAP errors that no repair could clear.
    Resolve the placement zone from the subsystem's architecture category, falling
    back to mapping the DB category to its coarse zone (via p08's alias table) and
    finally a default zone. Also give each placed part a unique designator.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
    [p13_placement.py]
2026-06-17 Fix frozen optimization loop: wire validator failures to effective repairs
    The critique->repair->validate loop never improved the design because the
    repair actions could not change the quantities that gate convergence.
    Root causes fixed:
    - ERC_UNPOWERED_VDD was permanent: every DB part (incl. power sources) got
    only POWER_IN pins, so no rail ever had a POWER_OUT driver. Power-source
    categories now expose a VOUT POWER_OUT pin (p06_component_db).
    - ERC errors were mapped to reroute_net (PCB copper), which can never clear a
    schematic ERC error. Added fix_erc handler operating on the netlist.
    - Over-temperature could not be lowered: added fix_thermal that reduces the
    hot part's effectiv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
    [checkpoint.py, models.py, p06_component_db.py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]
2026-06-17 Add checkpoint resume, verbose Gemini logging, and heavy->medium fallback
    - Resume: DesignState.from_dict + CheckpointManager.resolve + --resume CLI flag.
    Rebuilds state from a checkpoint (dir, base dir, or state.json) and skips the
    expensive setup phases, continuing from integration -> validation -> repair loop.
    - Gemini logging: per-attempt request log (tier/model/key/attempt/prompt size),
    explicit rate-limit (429), timeout, downgrade, and OK-with-elapsed logs so a
    slow call is clearly 'retrying' vs 'frozen'.
    - Per-request timeout (asyncio.wait_for) so a stuck call can never hang forever.
    - Real heavy->medium tier fallback when the primary tier is fully rate-limited.
    Co-Authored-B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
    [checkpoint.py, gemini_manager.py, models.py]
2026-06-18 Fix p21 simulation: exclude power-source parts from consumed-power sum
    The simulation power scenario gated on pwr_mw < 10000, but
    _sim_power_consumption summed voltage_max*current_ma over every selected
    part including the regulator/power-source. A power subsystem rated by its
    supply capacity (e.g. 20V/5000mA) injected ~100,000 mW of phantom load,
    making the gate mathematically unreachable; reduce_power cannot lower it
    because it (correctly) skips POWER-category parts.
    Exclude power-source categories from the consumed-power sum (and align the
    voltage-stability consumer set), matching p18_power's source/consumer split.
    With this, the existing reduce_power repairs converge simulation to 100%.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
    [p21_simulation.py]
2026-06-18 Make p18 power a first-class convergence signal
    Power validation was invisible to the optimization loop: the 'design is
    clean' gate and the design score only considered ERC/DRC/sim/temp/battery,
    and DesignMetrics had no field for whether p18_power passed. Consequences:
    - a design could be declared CLEAN while p18 reported PWR_OVER_BUDGET;
    - the improvement guard couldn't see power-budget progress, so the loop
    oscillated (trim power, re-add a ghost consumer) without registering it.
    Changes:
    - DesignMetrics gains power_ok (mirrors p18 pass/fail) and
    power_over_budget_mw (how far over the architecture budget).
    - p23_metrics populates both from the p18_power stage result.
    - or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
    [models.py, p23_metrics.py, p25_repair.py]
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2026-06-23 feat(android): complete Samvit Android app
    Implements all 8 goals from the Samvit spec:
    - Voice orchestration: perpetually-listening SpeechRecognizer + TTS pipeline
    - Deterministic matcher: Emergency / Mayday Mayday / Stop / Cancel / Heading To / Read Screen — bypass Gemini entirely
    - Gemini intent resolver: Class 2 natural language → structured action JSON
    - Accessibility service: screen reading + app launch + settings navigation via AccessibilityService
    - Emergency system: Tier 1 (Emergency) + Tier 2 (Mayday Mayday) with 5-second cancel window, SMS + calling
    - Reminder system: voice-set reminders via WorkManager (one-time + recurring), TTS delivery
    - Trusted contact bro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
2026-06-23 fix(backend/agent): batch memory disk writes; fix case-insensitive app name extraction
    - Replace per-mutation save() calls with a dirty-flag + debounce approach
    (_mark_dirty flushes at most every 5 s) to avoid synchronous disk I/O
    on every voice interaction (critical on slow SD cards / RPi)
    - Default AGENT_MEMORY_PATH to ~/.samvit/agent_memory.json so the file
    is no longer written to the repo root / CWD
    - Fix _fallback_action: split on lowercase "open" so Gemini-generated or
    normalised steps (e.g. "open whatsapp") are parsed correctly
    - Fix _update_memory_from_step: use case-insensitive step scan so the
    logged-in app name is extracted correctly regardless of casing
    - Add [CLARIFY]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
2026-06-23 fix(backend): replace global agent singleton with session-keyed instances
    - The module-level agent singleton was not thread-safe: concurrent
    /agent/plan requests clobbered each other's current_plan and
    action_history
    - Replace with a per-session VisionAgent registry keyed by
    X-Session-ID request header
    - /agent/plan now returns the sessionId so clients can pin subsequent
    requests to the same agent instance
    - Add call summarization stub endpoint POST /call/summarize
    (requires Android-side STT pipeline — see KNOWN_GAPS.md §1)
2026-06-23 fix(main): fix resolve_api_keys to match documented env var naming
    - The docstring said GEMINI_API_KEY_1 is the first key but the old
    implementation checked plain GEMINI_API_KEY first then _1, _2, …
    This could silently load zero keys if only _1/_2 were set (common
    .env.example pattern)
    - Now iterates GEMINI_API_KEY_1, _2, … first (matching the docs)
    and accepts plain GEMINI_API_KEY as a convenience alias so single-
    key setups do not need to rename their env var
2026-06-23 fix(android): remove deprecated PROCESS_OUTGOING_CALLS; annotate ACCESS_BACKGROUND_LOCATION
    - PROCESS_OUTGOING_CALLS was deprecated in API 29 (Android 10) and has
    no effect on any modern device. Removed. Use CallScreeningService if
    call interception is ever needed.
    - Added inline comment on ACCESS_BACKGROUND_LOCATION warning that the
    Play Store requires a separate declaration form justifying background
    location access before the app can be submitted
2026-06-23 fix(hardware): add first-frame timeout retry in camera read_grid; eliminate const_cast in I2C buffer
    camera_fusion.cpp:
    - read_grid() previously threw std::runtime_error immediately if no
    frame had been captured yet. The pipeline can call read_grid() right
    after start() before the capture thread delivers its first frame,
    crashing the vest. Now polls with 10 ms sleeps for up to 500 ms
    before throwing, giving the camera time to initialise.
    motor_driver.cpp:
    - raw_write() used const_cast<uint8_t*>(data.data()) to satisfy the
    i2c_msg::buf pointer. Some kernel I2C drivers write into the buffer
    for DMA alignment; casting away const on a truly const object is
    undefined behaviour. Cop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
    [motor_driver.cpp]
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2026-06-23 feat(emergency): add GPS broadcasting + CameraX forensics for Tier 1 & Tier 2
    Gap 1 — LocationBroadcastManager.kt (new):
    - Uses FusedLocationProviderClient.requestLocationUpdates() for active GPS
    (not the stale lastLocation()) every 15 seconds during an emergency.
    - On each fix, sends SMS to all trusted contacts with a Google Maps link,
    timestamp, and [EMERGENCY] or [MAYDAY] tier prefix.
    - EmergencyManager.triggerTier1() calls locationBroadcast.start().
    - EmergencyManager.triggerTier2() calls locationBroadcast.start(hyper=true).
    - EmergencyManager.resolveEmergency() stops updates and releases the callback.
    Gap 8 — AI camera forensics in EmergencyManager.triggerTier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
2026-06-23 feat(intent): add confidence scoring + reliable ambiguity resolution
    Gap 4 — ambiguity resolution:
    - ResolvedIntent gains confidence: Float (0.0–1.0).
    - System prompt updated to explicitly instruct Gemini: "If confidence < 0.85,
    set confirmation to a spoken question reflecting your interpretation."
    - CONFIDENCE_THRESHOLD = 0.85f constant defined.
    - parseJson() synthesises a fallback confirmation question when Gemini returns
    confidence < 0.85 but an empty confirmation string (belt-and-suspenders:
    low-confidence intents ALWAYS ask before acting).
    - RECALL_AUDIT action added to the prompt for "when was the dashboard last
    accessed" utterances.
    Gap 9 preview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
2026-06-23 feat(voice): add Porcupine always-on wake-word engine
    Gap 7 — perpetual listening:
    - PorcupineWakeWordEngine runs Picovoice Porcupine 3.0.1 on a daemon thread.
    - AudioRecord reads PCM frames continuously; engine.process() checks each frame.
    - On wake-word detection, calls orchestrator.speech.startListening() to hand
    off to SpeechRecognitionManager for one full command cycle.
    - Pauses frame processing (Thread.sleep) while orchestrator is SPEAKING or
    PROCESSING to avoid triggering on TTS output.
    - After the command cycle, the thread resumes Porcupine automatically —
    no silence-timeout gap between commands.
    - Gracefully no-ops with a WARN log if:
    (a) PORCUPIN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
2026-06-23 docs: close gaps 1-9 in KNOWN_GAPS.md; defer sub-3s AI cycle (gap 10)
    Mark gaps 1–9 as CLOSED with a brief summary of each fix.
    Gap 10 (sub-3-second on-device AI cycle) is deferred — requires ML-ops
    work (model selection, TFLite quantisation) outside this fix pass.
2026-06-23 fix(security): encrypt incident archive via shared SecurePrefs singleton
    Regression introduced in round 1: resolveEmergency() wrote the camera-forensics
    incident archive to plain getSharedPreferences("samvit_incidents"), bypassing the
    AES-256-GCM Keystore encryption set up in commit 2.
    Fix:
    - New SecurePrefs.kt object: singleton EncryptedSharedPreferences ("samvit_secure_prefs",
    AES256_GCM masterKey) shared across the whole app.
    - SamvitDatabase.getOrCreatePassphrase() now delegates to SecurePrefs.get(context)
    instead of creating its own EncryptedSharedPreferences — one Keystore key for both.
    - EmergencyManager.resolveEmergency() writes incident_{timestamp} via Secur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
2026-06-23 feat(voice): complete call summary dictation + Gemini formatting + recall
    Fix 2 — second half of the call summarization flow:
    VoiceOrchestrator:
    - callSummaryBuffer: StringBuilder accumulates dictated notes across utterances.
    - handleUtterance() dispatches on pendingConfirmation sentinel strings before the
    generic yes/no path: "call_summary_prompt" (yes/no gate) and
    "call_summary_dictation" (collect until "done" / "that's it" / "that's all").
    - processCallSummary() calls gemini.formatCallSummary() instead of the old stub;
    stores the result under call_summary_{timestamp} via repo.memorise().
    - New RECALL_CALL_SUMMARY intent handler: searches memory for call_summary_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
